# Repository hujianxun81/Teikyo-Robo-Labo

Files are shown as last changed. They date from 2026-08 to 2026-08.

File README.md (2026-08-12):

Engineering materials
====

This repository contains engineering materials of a self-driven vehicle's model participating in the WRO Future Engineers competition in the season 2026.

## Content

* `t-photos` contains 2 photos of the team (an official one and one funny photo with all team members)
* `v-photos` contains 6 photos of the vehicle (from every side, from top and bottom)
* `video` contains the video.md file with the link to a video where driving demonstration exists
* `schemes` contains one or several schematic diagrams in form of JPEG, PNG or PDF of the electromechanical components illustrating all the elements (electronic components and motors) used in the vehicle and how they connect to each other.
* `src` contains code of control software for all components which were programmed to participate in the competition
* `models` is for the files for models used by 3D printers, laser cutting machines and CNC machines to produce the vehicle elements. If there is nothing to add to this location, the directory can be removed.
* `other` is for other files which can be used to understand how to prepare the vehicle for the competition. It may include documentation how to connect to a SBC/SBM and upload files there, datasets, hardware specifications, communication protocols descriptions etc. If there is nothing to add to this location, the directory can be removed.

## Introduction

_This part must be filled by participants with the technical clarifications about the code: which modules the code consists of, how they are related to the electromechanical components of the vehicle, and what is the process to build/compile/upload the code to the vehicle’s controllers._

## How to prepare the repo based on the template

_Remove this section before the first commit to the repository_

1. Clone this repo by using the `git clone` functionality.
2. Remove `.git` directory
3. [Initialize a new public repository on GitHub](https://github.com/new) by following instructions from "create a new repository on the command line" section (appeared after pressing "Create repository" button).

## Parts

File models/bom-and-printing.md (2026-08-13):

# Bill of Materials & Printing

## 1. Purchased parts

CAD for every item below lives in `vendor-models/`. The **Mounted on** column says where each one ends up on the car.

### Chassis

| Part | Qty | Model / SKU | CAD file | Mounted on | Link |
|---|---|---|---|---|---|
| Motor | 1 | Hobbywing QuicRun Fusion Pro Elite | `motor-quicrun-fusion-pro.step` | Chassis | https://www.hobbywing.com/en/products/quicrun-fusion-pro-elite |
| Steering servo | 1 | YANTRS 0427 AS-MGX-E | `servo-as-mgx-e.step` | Chassis, ahead of front axle | https://yantrs.cn/products/yantrs-helical-1-8-1-10-rc-40kg-climbing-car-racing-car-high-torque-waterproof-brushless-servo-%E7%9A%84%E5%89%AF%E6%9C%AC |
| Battery | 1 | FULLYMAX 3S 11.1 V 1000 mAh 70C | `battery-3s-1000mah.step` | Chassis, battery bay | https://www.fullymaxbattery.com/china-3s-1000mah-lipo-battery-11-1v-70c-fpv-drone-helicopter-rc-model-battery-for-rc-car-35910738.html |
| Power switch board | 1 | MOSFET high-current switch | `power-switch-board.step` | Chassis | https://item.taobao.com/item.htm?id=761933378076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 |
| Y harness | 1 | Parallel battery lead | `y-harness.step` | Chassis, Power switch board | https://detail.tmall.com/item.htm?id=40903043930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 |
| Front wheels | 2 | Losi LOS41049 | `wheel-front-los41049.step` | Front axle | https://www.losi.com/product/losi-wide-body-rib-front-mounted-tires-white-2-mini-b/LOS41049.html |
| Rear wheels | 2 | Losi LOS41017 | `wheel-rear-los41017.step` | Rear axle | https://www.losi.com/product/losi-taper-pin-fr-mounted-white-2-mini-b/LOS41017.html |

### Tier 2

| Part | Qty | Model / SKU | CAD file | Mounted on | Link |
|---|---|---|---|---|---|
| LiDAR | 1 | YDLIDAR 4ROS | `lidar-ydlidar-4ros.step` | Tier 2 deck | https://category.yahboom.net/products/ydlidar-4ros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 |
| DC-DC converter | 1 | GODSEND GOD60-18S12B3R2-TS | `dcdc-god60.step` | Tier 2 deck | https://item.taobao.com/item.htm?id=521952280662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 |
| Cooling fan | 1 | FB Cr03 | `fan-fb-cr03.step` | Tier 2 deck, no fan mount | https://detail.tmall.com/item.htm?id=777437560260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 |

### Tier 3

| Part | Qty | Model / SKU | CAD file | Mounted on | Link |
|---|---|---|---|---|---|
| SBC (host) | 1 | NVIDIA Jetson Orin Nano Super | `sbc-jetson-orin-nano-super.step` | Tier 3 deck | https://www.hzhytech.com/AI-product/pd_232 |
| MCU board | 1 | Yahboom ROS Control Board V3.0 | `mcu-yahboom-ros-v3.step` | Tier 3, on camera mount | https://category.yahboom.net/collections/stm32/products/ros-driver-board |
| Depth camera | 1 | ORBBEC Gemini 336L | `depth-camera-gemini-336l.step` | Tier 3, on camera mount | https://www.orbbec.com/products/stereo-vision-camera/gemini-336l/ |
| USB hub | 1 | MixedSignal Lab SmartUSBHub 4CH | `usb-hub-4ch.step` | Tier 3 deck, front | https://item.taobao.com/item.htm?id=687666588208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 |
| LiDAR UART bridge | 1 | Silicon Labs CP210x | `uart-bridge-cp210x.step` | Tier 3 deck, bottom | https://item.taobao.com/item.htm?id=521952280662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 |

### Tier 2–3 interconnect brackets

| Part | Qty | Model / SKU | CAD file | Mounted on | Link |
|---|---|---|---|---|---|
| Display | 1 | DFRobot DFR0486 | `display-dfr0486.step` | Display mount | https://www.dfrobot.com/product-1576.html |
| Button | 1 | DFRobot DFR0991 | `button-dfr0991.step` | Button + ToF mount | https://www.dfrobot.com/product-2634.html |
| ToF rangefinder | 1 | DFRobot SEN0628 | `tof-sensor-sen0628.step` | Button + ToF mount | https://www.dfrobot.com/product-2999.html |
| Main switch | 1 | Zave KND-1-DF007-R2 | `power-switch-knd1.step` | Switch + voltmeter mount | https://detail.tmall.com/item.htm?id=825164395808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 |
| Voltmeter | 1 | CEDAR OLED micro voltmeter | `voltmeter-oled.step` | Switch + voltmeter mount | https://item.taobao.com/item.htm?id=1010575171136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 |

### Bearings & fasteners

| Part | Qty | Spec | Used in | Link |
|---|---|---|---|---|
| Bearing | 2 | MR117ZZ, ⌀11 × 7 × 3 mm | Rear axle carriers, inner | https://www.amazon.co.jp/dp/B07ZPVT411?ref=ppx_yo2ov_dt_b_fed_asin_title&th=1 |
| Bearing | 2 | MR74ZZ, ⌀7 × 4 × 2.5 mm | Rear axle carriers, outer | https://www.amazon.co.jp/dp/B07NXPL9GL?ref=ppx_yo2ov_dt_b_fed_asin_title&th=1 |
| Bearing | 4 | MR74ZZ, ⌀7 × 4 × 2.5 mm | Steering knuckles, 2 each | https://www.amazon.co.jp/dp/B07NXPL9GL?ref=ppx_yo2ov_dt_b_fed_asin_title&th=1 |
| Screws | — | M3 | Throughout | https://www.amazon.co.jp/dp/B0742DDLQ1?ref=ppx_yo2ov_dt_b_fed_asin_title |

---

## 2. Printing

### 2.1 Profiles

| | PETG (verification) | PA12-CF (final) |
| --- | --- | --- |
| Filament | Inslogic PETG Pro | Inslogic PA12-CF |
| Nozzle diameter | 0.4 mm, Tungsten Carbide Nozzle, High Flow | **0.6 mm, hardened steel, Standard** |
| Layer height | 0.2 mm | 0.3 mm |
| Walls | 3 | **2** |
| Top / bottom solid layers | 6 / 6 | **4 / 4** |
| Infill | 15–20 % gyroid | 15–20 % gyroid |
| Nozzle temp | 240 °C | **270 °C** (first layer 275 °C) |
| Bed temp | 65 °C (Texture PEI Plate) | **90 °C** (Engineering Plate) |
| Chamber | — | **50 °C, exhaust fan OFF** |
| Max volumetric speed | default | **8 mm³/s** (≈ 43 mm/s effective) |

Wall counts differ because the nozzle does: 3 × 0.42 mm ≈ 2 × 0.62 mm ≈ 1.25 mm of wall either way; Same for the solid layers: 6 × 0.2 = 4 × 0.3 = 1.2 mm of skin.

Do not raise infill above ~20 % on flat plates. Bending stiffness comes from the top and bottom skins; at 4 mm thickness the core contributes under 0.5 %. Add solid layers instead — lighter and stiffer per gram.

PA12-CF is roughly twice the flexural modulus of PETG at 83 % the density, so a plate can be about 20 % thinner for the same stiffness (4.0 mm PETG ≈ 3.2 mm PA12-CF, and 34 % lighter).

### 2.2 PA12-CF setup

Getting this material to stick took several attempts. All of the following matter:

| Step | Detail |
| --- | --- |
| Dry the filament | 85 °C for 12 h **before** printing, then keep it in the dryer and feed through PTFE. Drying while printing does not remove water, it only maintains. |
| Wash the plate | Use Isopropyl alcohol to remove finger oil from the textured surface. |
| Glue | Preheat plate to 60 °C, apply Magigoo PA thinly, let it dry to a film. |
| Bed temperature  | **90 °C** on the Engineering Plate. The 60–70 °C in the TDS assumes a Textured PEI Plate; the Engineering Plate is designed for a higher range and adheres poorly at 65 °C. |
| Chamber | 50 °C, and make sure the chamber exhaust fan is off or it defeats the heater. |
| Brim | 8 mm outer brim, **gap 0**. A gap means the brim is not anchoring anything. 5 mm is enough for small parts. |

Other slicer settings that were needed:

| Setting | Value | Why |
| --- | --- | --- |
| Part cooling fan | 0 % on normal layers | Cooling is what causes warping in nylon |
| Overhang / bridge fan | 40 % | Needed so top skins don't sag into the infill |
| Cooling overhang threshold | 50 % | At 0 % it flags ordinary outer walls as overhangs and blows on them |
| First layer speed | 20 mm/s (infill 30 mm/s) | Only speed that isn't capped by the volumetric limit, and it drives adhesion |
| Acceleration | normal 3000, outer wall 2000, travel 5000, first layer 500 | High acceleration knocks marginally-attached parts loose |
| First layer line width | 0.68 mm | More contact area with the plate |
| Elephant foot compensation | 0 | It shrinks the first layer, which is the opposite of what we want |
| **Auto circular hole compensation** | **OFF** | Would silently resize every bore and invalidate the calibration below |
| **X-Y size compensation** | **0** | Same reason |
| Seam position | Random on structural parts | Aligned seams stack into a vertical weak line |

The purge line at the front of the plate is disabled — the `G130 ... L40 E12 D4` line in the machine start G-code is commented out. It was being dragged into the part. Safe to disable because every part is printed with a brim, so any under-extrusion at the start lands on the brim. Re-check this after a Bambu Studio update.

### 2.3 Per-part orientation

| Part | Orientation | Notes |
| --- | --- | --- |
| `rear-axle-carrier-left/right` | Wall-plate face down | Bearing bore axis vertical → round bore. 3 walls locally: the MR117 seat wall is only ~1.3 mm |
| `steering-knuckle-left/right`  | Bearing bore axis vertical | Matches the fit gauge orientation |
| `steering-deck-lower/upper` | Flat | Integral ball sockets at both ends |

### 2.4 Fit calibration

**Re-run the gauges whenever the material *or* the nozzle diameter changes.** The offset
below is not material shrinkage — it is nearly constant across bore sizes, which means it
comes mostly from extrusion width.

| Feature | Nominal | PETG @0.4 | PA12-CF @0.6 |
| --- | --- | --- | --- |
| MR117ZZ seat | ⌀11.00  | 11.10 | **11.40** |
| MR74ZZ seat | ⌀7.00 | 7.10 | **7.40** |
| Ball socket (ball ⌀4.8) | — | 5.00 | **5.45** |

Gauges: `cad/test-coupons/bearing-fit-gauge-*.step`, `rod-end-fit-gauge-*.step`

Notes:

- Every bearing seat gets a **0.4–0.5 mm × 45° lead-in chamfer**. Without it the bearing has to be driven in with a hammer.
- Bearing shoulders stay square. No fillet, or the bearing will not seat flat.
- **Spherical cavities need about 0.15 mm more compensation than a cylindrical bore of the same size** (0.45 vs 0.30 here). The upper hemisphere is an unsupported dome that droops inward as it prints. Apply this to any ball socket, not just rod ends.

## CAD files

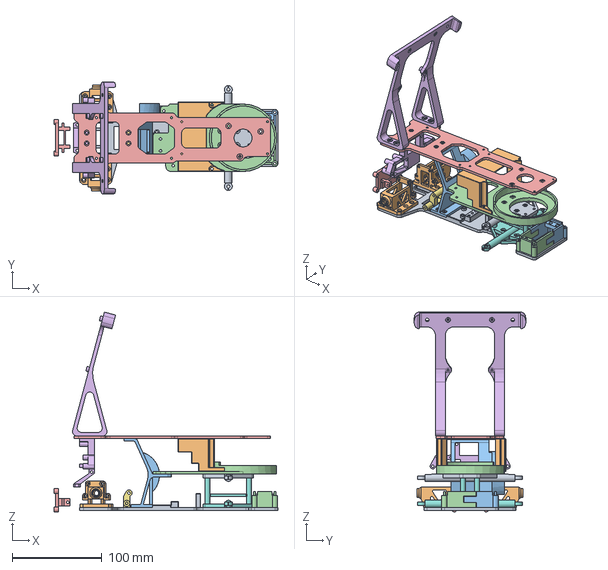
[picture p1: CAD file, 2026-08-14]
models/complete-vehicle-frame-assembly.step
250.0 x 124.6 x 223.1 mm

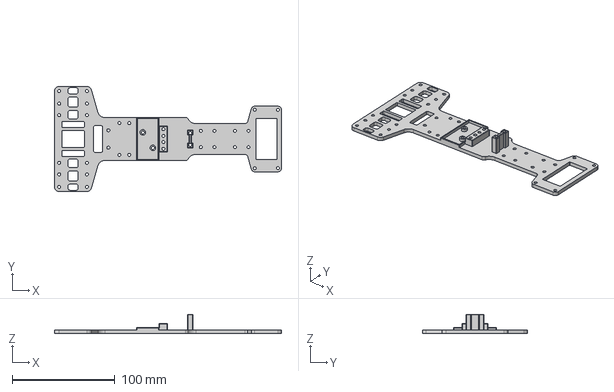
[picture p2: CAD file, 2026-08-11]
models/cad/chassis/chassis-plate.step
221.4 x 102.6 x 19.0 mm

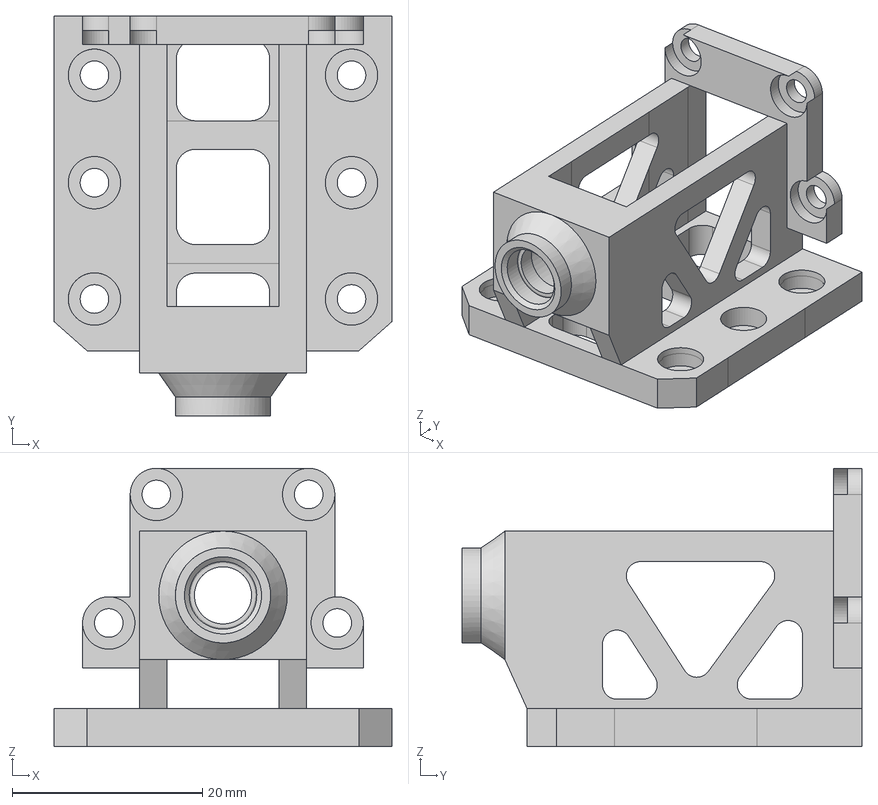
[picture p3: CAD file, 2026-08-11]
models/cad/chassis/drivetrain/rear-axle-carrier-left.step
35.5 x 42.0 x 29.2 mm

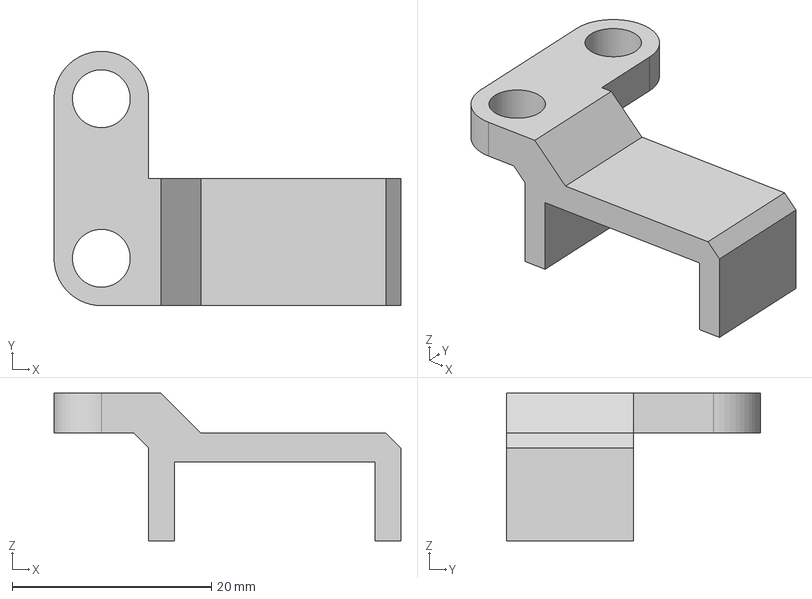
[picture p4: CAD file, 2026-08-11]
models/cad/chassis/steering/servo-mount-upper.step
34.8 x 25.5 x 14.8 mm

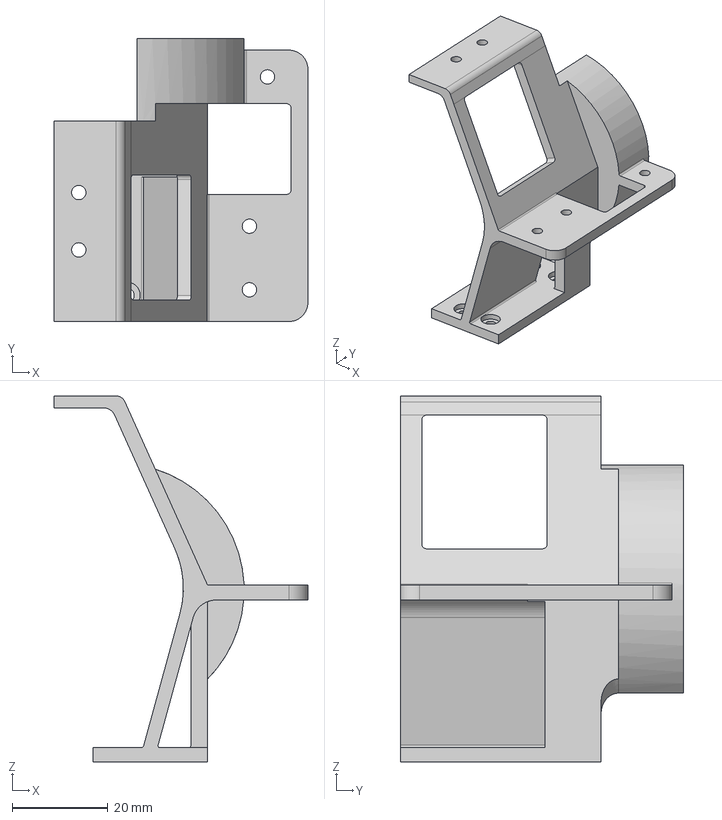
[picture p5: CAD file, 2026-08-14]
models/cad/superstructure/interconnect/tier2-3-interconnect-frame.step
53.1 x 59.3 x 76.6 mm

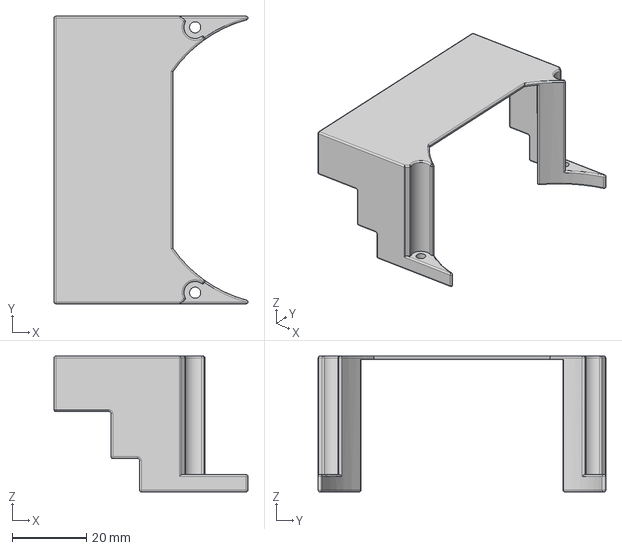
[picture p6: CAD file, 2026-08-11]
models/cad/superstructure/tier2/fan-mount.step
52.2 x 77.4 x 36.6 mm

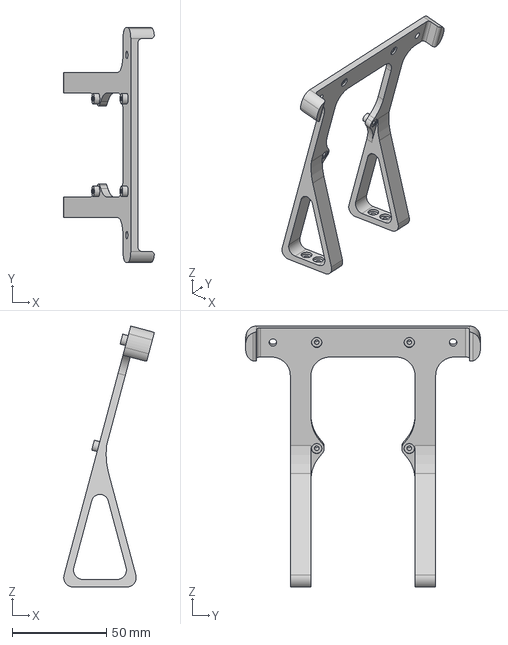
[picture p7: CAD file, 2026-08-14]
models/cad/superstructure/tier3/camera-mount.step
48.0 x 124.7 x 138.4 mm

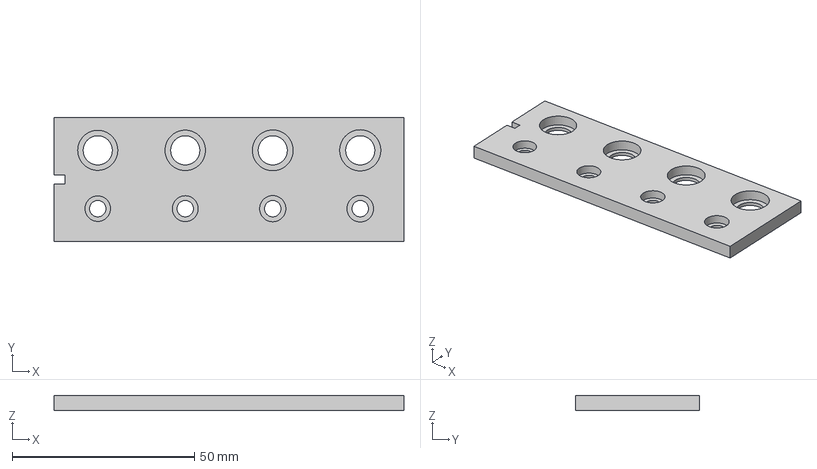
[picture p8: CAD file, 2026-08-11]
models/cad/test-coupons/bearing-fit-gauge.step
96.0 x 34.0 x 4.00 mm

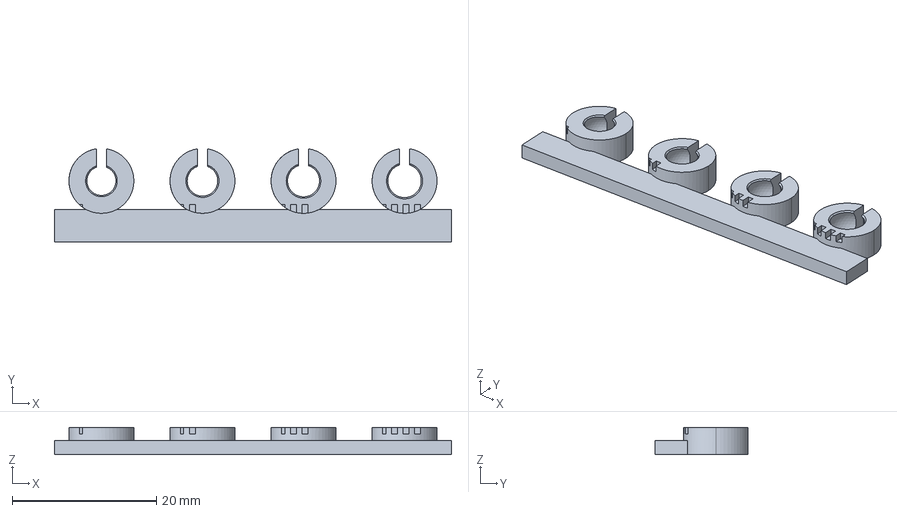
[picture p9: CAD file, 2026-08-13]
models/cad/test-coupons/PA12-CF/rod-end-fit-gauge-v2.step
55.0 x 12.9 x 3.80 mm

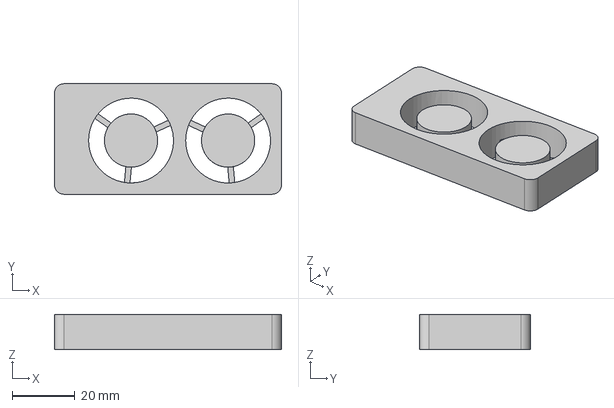
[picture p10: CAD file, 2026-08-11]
models/vendor-models/fan-fb-cr03.step
72.5 x 35.3 x 11.2 mm

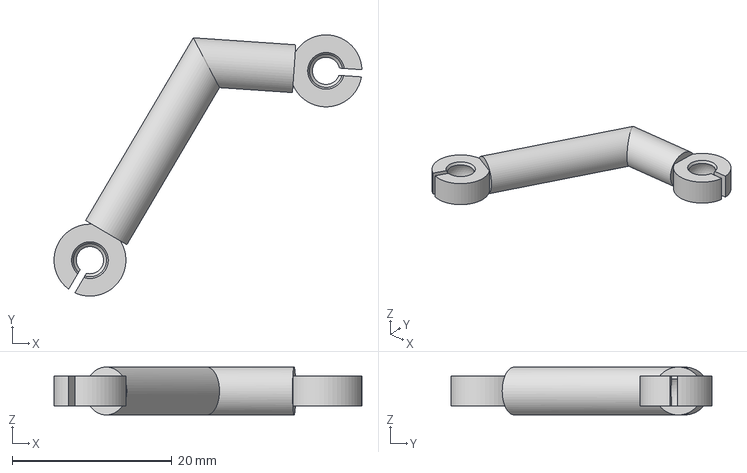
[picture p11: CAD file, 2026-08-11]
models/cad/chassis/steering/tie-rod-right.step
38.5 x 32.7 x 6.00 mm

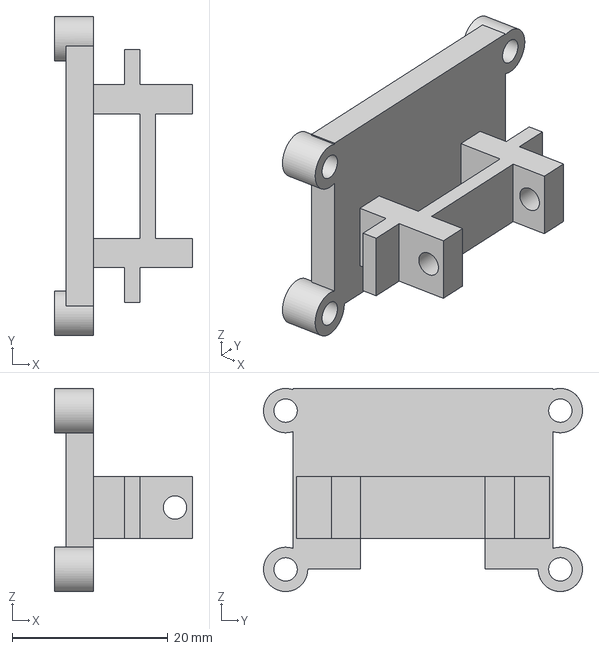
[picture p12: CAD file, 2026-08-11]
models/cad/superstructure/interconnect/display-mount.step
17.7 x 41.0 x 26.1 mm

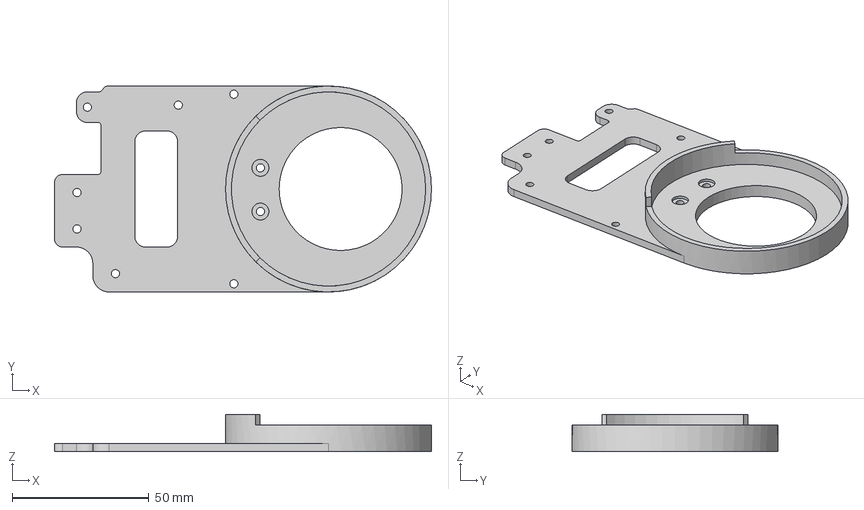
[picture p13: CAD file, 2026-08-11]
models/cad/superstructure/tier2/tier2-deck.step
138.0 x 75.4 x 13.7 mm

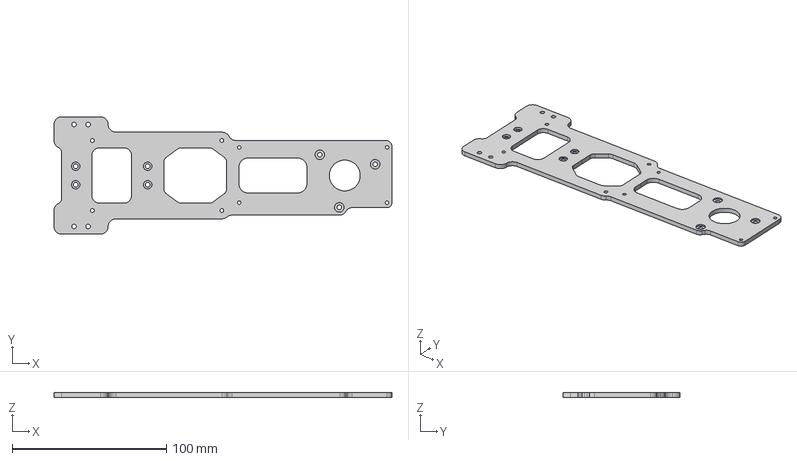
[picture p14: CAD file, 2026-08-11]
models/cad/superstructure/tier3/tier3-deck.step
219.2 x 76.1 x 3.00 mm

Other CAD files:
models/cad/chassis/drivetrain/rear-axle-carrier-right.step
models/cad/test-coupons/PA12-CF/bearing-fit-gauge-mr74.step
models/cad/test-coupons/rod-end-fit-gauge.step
models/vendor-models/sbc-jetson-orin-nano-super.step
models/cad/chassis/drivetrain/motor-mount-front.step
models/cad/chassis/drivetrain/rear-axle-shaft.step
models/cad/chassis/steering/servo-mount-lower.step
models/cad/chassis/steering/servo-mount.step
models/cad/chassis/steering/servo-pushrod.step
models/cad/chassis/steering/steering-deck-lower.step
models/cad/chassis/steering/steering-deck-upper.step
models/cad/chassis/steering/steering-knuckle-left.step
models/cad/chassis/steering/steering-knuckle-right.step
models/cad/chassis/steering/tie-rod-left.step
models/cad/superstructure/interconnect/button-tof-mount.step
models/cad/superstructure/interconnect/switch-voltmeter-mount.step
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

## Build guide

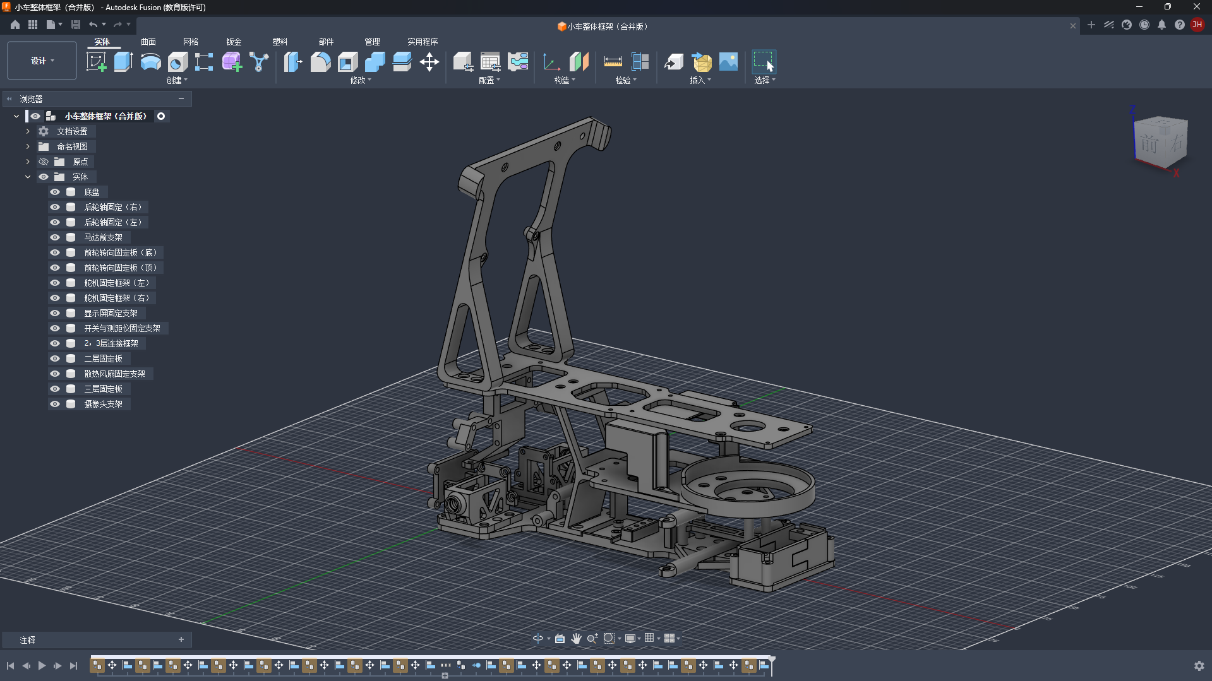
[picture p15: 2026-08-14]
models/complete-vehicle-frame-assembly.png
